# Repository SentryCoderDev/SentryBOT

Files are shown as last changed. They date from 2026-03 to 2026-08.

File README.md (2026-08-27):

# <p align="center">
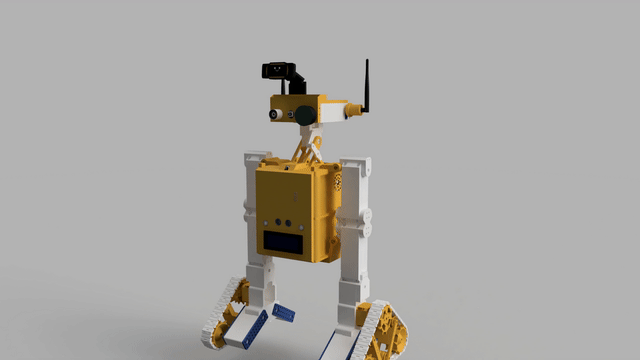
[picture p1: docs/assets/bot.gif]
SentryBOT demo
  
</p>

# SentryBOT – Modüler İki Ayaklı Yoldaş Robot Platformu













SentryBOT; Raspberry Pi 5 + Arduino tabanlı, modüler bir yoldaş robot ve servis mimarisidir. Tüm yetenekler bağımsız modüller hâlinde tasarlanır, tek bir Gateway üzerinden tek porttan API olarak sunulur. Donanım kontrolü Arduino ile yapılırken; konuşma tanıma/TTS, LED animasyonları, kamera ve LLM/RAG gibi fonksiyonlar Pi5 üzerinde mikro servisler olarak çalışır.

Ana hedefler:
- Basit, temiz, DryCode odaklı modüller
- Her modül hem kütüphane (import) hem servis (run) olarak çalışabilir
- Tüm konfigürasyonlar YAML dosyalarındadır ve gerektiğinde override edilebilir
- Donanım ağır işlerini Arduino üstlenir; görüntü işleme gibi pahalı işler gerekiyorsa dış istemcilere (PC) köprülenir

## Neler Yeni? (Öne Çıkan Son Geliştirmeler)

- **Tri-Layer Agent Mimarı (agent_core):** Robotun otonom kararları 3 katmanlı (Router/Planner, Uzman Sub-Agent'lar, Ana Persona) bir otonom ajan pipeline'ı ile yönetilir.
- **Social DB:** Eski JSON tabanlı izole hafızalar tek bir birleşik SQLite veritabanında toplandı. Kişiler, yüzler, ilişkiler, anılar ve ritüeller tek merkezden yönetiliyor.
- **OLED Faces:** SSD1306 I2C OLED için Pip tarzı prosedürel animasyonlu göz ve yüz ifadeleri eklendi. Duygusal ifadeler robotun durumuyla senkronize edilir.
- **Gelişmiş Otonomi ve Duygu Motoru (autonomy):** Robotun iç durumu (Mutluluk, Enerji, Merak, Korku) davranışlarını ve NeoPixel ışıklarını otomatik etkiler. Ses geldiğinde kafa çevirme, boşta kalınca iç çekme/etrafı izleme özellikleri aktiftir.
- **Wakeword Modülü:** OpenWakeWord destekli düşük güçlü arka plan dinleyicisi eklendi.
- **Semantik Router:** İstekler LLM tabanlı vektör/benzerlik ile en doğru sub-agent'a yönlendirilir.
- **Common Emotion Vocab:** Tüm modüller ortak bir duygu (emotion) sözlüğünü kullanır; gözler, ışıklar ve ses tonu birbiriyle uyumlu çalışır.
- Servo sürüşü I2C’ye taşındı (PCA9685, 50 Hz). Açı→mikrosaniye darbe haritalaması konfigüre edilebilir (min/max us).
- Çift “X‑cross” lazer eklendi: tekli ya da ikisi birden aç/kapa (firmware komut + Pi API).
- **Tam Yapılandırılmış Çıktı (Structured JSON)**: Ollama artık tüm yanıtlarını düşünce, vokal yanıt ve aksiyon içeren JSON formatında döner.
- **Sistem-Genel Modül Kontrolü**: Robot kendi modüllerini LLM kararlarıyla çalışma esnasında kapatıp açabilir.
- **Durum Kalıcılığı**: State Manager, global state'i sqlite/json backend ile restart sonrasında da saklar.
- **Gateway Güvenliği**: Gateway'e isteğe bağlı API anahtarı ve rol kontrolü eklendi; yazma uçları korunabilir.
- **VLM Mode Yönetimi**: Görüntü işleme yetenekleri ayrı ayrı açılıp kapatılabilir; pahalı işlemler ihtiyaca göre sınırlandırılır.
- **Multimodal Animasyon Senkronizasyonu**: Tek YAML akışında servolar, OLED göz ifadeleri ve NeoPixel ışık efektleri zaman uyumlu (time-coded) çalışır.

## Mimari Genel Bakış

- Donanım: Raspberry Pi 5 (ana bilgisayar) + Arduino (ör. Mega) kontrol kartı
- İletişim: Arduino ile NDJSON seri köprü; modüller arası HTTP (FastAPI)
- Gateway: Tüm modül router’larını tek FastAPI sürecinde birleştirir (varsayılan: 0.0.0.0:8080)
- Konfigürasyon: Her modül altında `config/config.yml`; merkezi düzenleme için Config Center
- Loglama: Merkezi log wrapper; dosya + bellek içi halka buffer

Başlatıcı akış (varsayılan): `sentrybot.py` -> TUI (Control Center) arayüzünü başlatır ve arka planda run_robot.py'yi çalıştırır.

## Robot Ne Yapar? (Yetenekler)

Algılama, karar ve ifade zinciriyle çalışan SentryBOT’un yetenekleri modüllere ayrılmıştır. Aşağıda her bir alan için kapsam, tipik veri akışı, önemli uç noktalar ve sınırlar özetlenmiştir.

- Hareket/Donanım
	- Arduino Seri Köprü (modules/arduino_serial)
		- Kapsam: servo/stepper sürüş, IK pozları, otur/kal kalk, IMU okuma, telemetry, emergency stop.
		- Veri akışı: Pi5 ↔ Arduino NDJSON satır tabanlı mesajlar; arkaplanda non-blocking okuyucu, heartbeat.
		- Örnek: POST `/arduino/request` body `{ "cmd": "set_pose", "pose":[...], "duration_ms":1200 }`
		- Sınırlar: Seri port stabilitesi; AUTO port bulma başarısızsa `ARDUINO_PORT` ile zorlayın.
	- PiServo “Kulaklar” (modules/piservo)
		- Kapsam: sol/sağ servo ile duygu jestleri ve basit jestler (wakeword/sound).
		- API: `/piservo/set?left=90&right=90`, `/piservo/emotion?name=joy`
		- Sınırlar: Donanım yoksa simülatör modunda çalışır; PWM/angle sınırları config ile belirlenir.
	- Teşhis & Zamanlama (modules/diagnostics, modules/scheduler)
		- Diagnostics API: `/diagnostics/run`, `/diagnostics/report` — modül sağlıklarını zincir hâlinde kontrol eder; gecikme ve tekrar eden hataları da değerlendirir.
		- Scheduler API: `/scheduler/jobs` — basit async periyodik görevler, HTTP ping işleri; runtime görev ekleme/silme de desteklenir.

- Duyular
	- Kamera (modules/camera)
		- Kapsam: PiCamera2/OpenCV backend; çözünürlük, FPS, JPEG kalitesi ayarlanabilir, son kare yayımcısı.
		- Kullanım: Gateway ile `/camera/*` altında stream ve snapshot uçları (modül README’sine bakın).
		- Sınırlar: PiCamera2 sürücü/firmware gereksinimleri; düşük ışıkta hız/kalite ayarı gerekebilir.
	- VLM Bridge (modules/vlm_bridge)
		- Kapsam: OpenCV tabanlı yüz algılama/tanıma ve takip; dış işlemci sonuçlarını Pi5’e HTTP ile yollar.
		- API: `POST /vlm/track { head_tilt, head_pan, drive? }` → Arduino “track” komutuna köprü.
		- Not: `POST /vlm/mode` ile objects/people/ocr/depth gibi yetenekler tek tek açılıp kapatılabilir.
		- Sınırlar: Ağ gecikmesi; kontrol döngüsünde stabilite için sınırlamalar (slew/ölü bant) önerilir.
	- Konuşma Tanıma (modules/speech)
		- Kapsam: SpeechRecognition ile çok dilli Google STT; I2S mikrofon; stereo’da DoA hesaplar.
		- API: `/speech/start`, `/speech/stop`, `/speech/last`, `/speech/direction`, `/speech/track/*`
		- Veri akışı: ALSA → çerçeveler → SpeechRecognition / Google STT → metin; stereo ise GCC-PHAT → açı.
		- Sınırlar: DoA için stereo şart.
	- Telemetri & Durum (modules/telemetry, modules/state_manager)
		- Telemetry: `/telemetry/metrics` Prometheus; `/telemetry/events` ham olay yayımı.
		- State Manager: `/state/get`, `/state/set/emotions`, `/state/set/<key>` — global durum ve duygular için kalıcı anahtar/değer desteği.

- İfade/Arayüz
	- Speak (TTS) (modules/speak)
		- Kapsam: pyttsx3 veya Piper ile offline TTS; base64 WAV oynatma; ALSA çıkış cihazı seçimi.
		- API: `/speak/say { text, engine? }`, `/speak/play { data: base64-wav }`
		- Sınırlar: Piper için model/binary gerekir; ses cihazı eşleşmesi (ALSA) şarttır.
	- NeoPixel (modules/neopixel)
		- Kapsam: Donanım/simülatör otomatik; ileri seviye animasyonlar ve duygusal renk paletleri.
		- API: `/neopixel/fill`, `/neopixel/effect`, `/neopixel/emote`, `/neopixel/animate`
		- Sınırlar: LED sayısı ve hız config’den alınır; ağır animasyonlarda CPU yükü artabilir.

		# NeoPixel API (user-facing notes)
		- `GET /neopixel/animations` — returns a curated, human-friendly list of available animations. Use `?show_all=true` to see every registered animation key.
		- `GET /neopixel/emotions` — returns a simple list of emotion names (e.g. `admiration`, `joy`). Color codes are intentionally hidden from the UI; the service will pick a random palette variant when an emotion is triggered.
		- `POST /neopixel/animate` — accepts a JSON body with fields `name` (animation key), optional `color` ("R,G,B" or "#RRGGBB") or `r,g,b` channels, optional `emotions` (list) and `iterations`.
		  Example body: `{ "name": "WAVE", "color": "0,255,255", "iterations": 2 }`
		- `POST /neopixel/emote` — convenience endpoint. Accepts `emotion` (single name), `emotions` (list) or `text`. If an `emotion` is provided, the server will randomly select one of the palette variants for that emotion and display it (no palette codes are returned in the API response for UI simplicity).
		- Behavior: The driver will attempt to play animations using the native Pi driver when available (hardware-accelerated). If the native driver does not support an animation name the server will fall back to Python implementations.
	- Interactions (modules/interactions)
		- Kapsam: Kurallara göre NeoPixel efektleri tetikleme; CPU sıcaklık/yük, ağ burst, olaylar.
		- API: `/interactions/event`, `/interactions/effect`, `/interactions/base`, `/interactions/state`
		- Sınırlar: NeoPixel servisi yoksa no-op; gelişmiş segment/mask için API genişlemesi önerilir.
	- Animasyon (modules/animate)
		- Kapsam: YAML tanımlı servo poz sekansları; `xAnimateService.run('name')` ile tetikleme.
		- Şema örneği: `name`, `loop`, `steps[{ pose[], duration_ms|hold_ms }]`.
	- Bildirimler (modules/notifier)
		- Kapsam: Telegram/Discord köprüleri; test ucu ve basit metin gönderimi.
		- API: `/notify/telegram`, `/notify/discord`, `/notify/test`

- Zeka
	- LLM (Ollama) (modules/ollama)
		- Kapsam: Kişilik (persona) yönetimi ile LLM sohbet; modül içi persona klasör yapısı.
		- API: `/ollama/chat`, `/ollama/persona`, `/ollama/personas`, `/ollama/persona/select`
		- Veri akışı: Speech → Ollama.chat → Speak; Interactions/NeoPixel opsiyonel duygusal tepki verebilir.

## Hızlı Başlangıç

1) Bağımlılıkları yükle (opsiyonel kolay kurulum scriptleri):
	 - Windows PowerShell veya Linux’ta kök dizinden çalıştırın: `install_all_requirements.py` ya da `install_all_requirements.sh`
	 - Donanım/harici yazılımlar (piper, ffmpeg, avrdude vb.) için ilgili modül README’lerine bakın

2) Gateway’i başlat (önerilen üretim modu):
	 - `python run_robot.py`
	 - Varsayılan adres: `http://localhost:8080`
	 - Örnek sağlık kontrolleri: `/neopixel/healthz`, `/speech/healthz`, `/arduino/healthz`

3) Tek modül olarak çalıştırma (geliştirme/test):
	 - Örnek: NeoPixel Servis → `uvicorn modules.visual_output.neopixel.xNeopixelService:create_app --factory --host 0.0.0.0 --port 8092`
	 - Örnek: Speech API → `python -m modules.voice.speech.xSpeechService --api`

Notlar:
- RPi5 üzerinde ALSA ses cihazları ve I2S mikrofon kart(lar)ı için sistem düzeyinde ayarlar gerekebilir (modül README’lerine bakın).
- Arduino bağlantısı için port otomatik bulunur; gerekirse `ARDUINO_PORT` ve `ARDUINO_BAUD` ile override.

## Docker ile Çalıştırma

Kök dizinde hazır Docker dosyaları bulunur:
- `Dockerfile`
- `docker-compose.yml`
- `modules/gateway/config/config.docker.yml`
- `docker-compose.full.yml`
- `modules/gateway/config/config.docker.full.yml`
- `docker-compose.rpi.yml`
- `modules/gateway/config/config.docker.rpi.yml`

1) Build + başlat:
	- `docker compose up --build -d`
2) Logları izle:
	- `docker compose logs -f sentrybot-gateway`
3) Durdur:
	- `docker compose down`

Varsayılan Docker konfigürasyonu donanım bağımlı modülleri kapalı getirir ve API çekirdeğini başlatır.

Full profil (tüm modüller include, autostart kapalı):
- `docker compose -f docker-compose.yml -f docker-compose.full.yml up --build -d`

Raspberry Pi 5 + Arduino profili (donanım modülleri açık):
- `docker compose -f docker-compose.yml -f docker-compose.rpi.yml up --build -d`

- Sağlık kontrolü: `http://localhost:8080/healthz`
- Swagger UI: `http://localhost:8080/docs`
- ReDoc: `http://localhost:8080/redoc`
- Modül include ayarlarını değiştirmek için `modules/gateway/config/config.docker.yml`, `modules/gateway/config/config.docker.full.yml` veya `modules/gateway/config/config.docker.rpi.yml` dosyalarını düzenleyin.
- Alternatif bir gateway config kullanmak için `GATEWAY_CONFIG` environment variable’ını override edin.
- Raspberry Pi/Linux cihaz eşlemeleri `docker-compose.rpi.yml` içinde hazırdır.

## Konfigürasyon

- Gateway yapılandırması: `modules/gateway/config/config.yml`
	- `server.host / server.port` (varsayılan: 0.0.0.0:8080)
	- `include.<module>` anahtarları ile modülleri aç/kapat
- Modül yapılandırmaları: Her modül altında `config/config.yml`
	- Örnek env değişkenleri: `ARDUINO_PORT`, `ARDUINO_BAUD`, `NEO_DEVICE`, `NEO_NUM_LEDS` …
- Canlı düzenleme: Config Center UI → `/config/ui` (Gateway açıkken)

## API Haritası (Özet)

Gateway açıkken tüm modül uçları tek porttadır. Genel sağlık uçları: `/<modül>/healthz`.

- Arduino Seri: `/arduino/*` – hello, request/send, telemetry
- VLM Bridge: `/vlm/track` – dış işlemci komut köprüsü
- Kamera: `/camera/*` – API/stream
- NeoPixel: `/neopixel/*` – efektler, duygular, animasyon
- Interactions: `/interactions/*` – kural motoru, event tetikleme
- Speak (TTS): `/speak/*` – say/play
- Speech (ASR/DoA): `/speech/*` – tanıma başlat/durdur, yön, takip
- Ollama: `/ollama/*` – chat, persona yönetimi
- PiServo: `/piservo/*` – kulak jestleri
- Telemetry: `/telemetry/*` – Prometheus `/metrics`, event
- Diagnostics: `/diagnostics/*` – self-check ve rapor
- State Manager: `/state/*` – global durum/emotions
- Scheduler: `/scheduler/*` – iş listesi
- Scheduler: `/scheduler/*` – iş listesi, dinamik görev ekleme/silme ve sonuç takibi
- Notifier: `/notify/*` – Telegram/Discord köprüleri
- Config Center: `/config/*` – YAML okuma/düzenleme, UI

Detaylar ve örnek istekler her modülün README’sinde mevcuttur.

## Donanım Özeti ve Notlar

- RPi5 ana bilgisayar, Arduino (ör. Mega) USB ile bağlı
- I2S mikrofon(lar) (stereo önerilir) → Offline ASR ve DoA için
- MAX98357A I2S DAC → hoparlör çıkışı (Speak modülü)
- WS2812/NeoPixel şerit + Jewel (7) + Stick (16) varsayılan haritalama
- İki mini servo (kulaklar) → PiServo
- Kamera: PiCamera2 veya USB Webcam (auto seçimi desteklenir)
- Görüntü işleme ağır ise bir PC’ye stream + VLM Bridge ile komut köprüleme

## Arduino Firmware Özeti ve Donanım Detayları

Arduino tarafı gerçek zamanlı I/O ve hareket kontrolünden sorumludur. NDJSON tabanlı satır‑satır komutlarla çalışır.

- I2C Servo Sürüş (PCA9685)
	- Frekans: 50 Hz. Kanallar: 0–15 (konfigürasyonla atanır).
	- Konfig makroları (örnek): `SERVO_USE_PCA9685=1`, `PCA9685_ADDR=0x40`, `SERVO_MIN_US=500`, `SERVO_MAX_US=2500`.
	- detach/reattach ve tam‑kapat (full‑off) kenar durumları ele alınmıştır.
- Lazerler (iki adet X‑cross)
	- Firmware komutu: `{ "cmd":"laser", "id":1|2, "on":true }`, `{ "cmd":"laser", "both":true, "on":true }`, `{ "cmd":"laser", "on":false }`.
	- Pi tarafı API: `/arduino/laser/one/{1|2}`, `/arduino/laser/both`, `/arduino/laser/off` (gateway altında).
- LCD 16×1 ekranlar
	- Donanımsal olarak 8×2 gibi adreslenir; 16 karakterlik satırlar 8+8 olarak yazdırılır (kutucuk sorunu çözülür).
- Ultrasonik, IMU, PID, Stepper
	- Komut yüzeyi: `set_servo`, `set_pose(duration)`, `leg_ik`, `stepper(pos/vel/cfg)`, `home/zero`, `pid on/off`, `stand/sit`, `imu_read/cal`, `eeprom save/load`, `tune`, `policy`, `track`, `telemetry_*`, `get_state`, `estop`.

Donanım bağlamaya dair pratik notlar:
- Pi↔Arduino seviye dönüştürücü yönü doğru olmalı (Pi→LV, Arduino→HV hatları). I2C için pull‑up’lar tek tarafta yeterlidir.
- PCA9685 beslemesi ve servo güç hattı kalın iletken ve ortak GND ile bağlanmalıdır.

## Hızlı API Örnekleri

Gateway çalışıyorsa tüm uçlar tek porttadır. Aşağıdaki istekler örnektir:

- Lazerleri kontrol et (Arduino üzerinden)
	- Tek lazer: POST `/arduino/laser/one/1`
	- Her ikisi: POST `/arduino/laser/both`
	- Kapat: POST `/arduino/laser/off`

- NeoPixel duygusal renk gösterimi
	- POST `/neopixel/emote` body: `{ "text": "joy curiosity", "duration": 0.25 }`

- Görüntü işleme köprüsü (dış istemci → servo)
	- POST `/vlm/track` body: `{ "head_pan": 20, "head_tilt": -5 }`

- Konuşma
	- ASR başlat/durdur: `/speech/start`, `/speech/stop`
	- TTS: `/speak/say` body: `{ "text": "Merhaba!" }`
	## Modüller (Tek Tek)

	- **agent_core**: 3-katmanlı LLM tabanlı otonom zekâ (Router, Sub-agents, Persona) ve epizodik bellek yönetimi.
	- **ai_provider**: (eski adıyla ollama) LLM sohbet ve persona yönetimi; LLM endpointleri.
	- **arduino_serial**: Arduino Mega ile NDJSON seri köprü. Servo, stepper, imu, telemetry ve lazer kontrolü (esp_link'i içerir).
	- **autonomy**: Live Mode. Duygu durum yönetimi (MoodManager), davranış döngüsü, VLM algı birleştirme ve otonom tepki/sahne yöneticisi.
	- **calibration**: Servo, Kamera ve Ses kalibrasyon yardımcıları.
	- **camera**: PiCamera2/OpenCV backend ile görüntü yakalama ve yayın.
	- **cognitive_memory**: (eski adıyla social_db) Kişiler, ilişkiler, görülme kayıtları, sohbet geçmişi ve anıları tek merkezde toplayan birleşik SQLite bellek.
	- **common**: Ortak yardımcılar, paylaşılan duygu/ifade (emotion) sözlüğü (`emotion_vocab.py`).
	- **expression**: Semantik ifade motoru. Sistem olaylarını senkronize animasyon, renk ve oled yüz ifadelerine dönüştürür (interactions'ı içerir).
	- **gateway**: Ana giriş noktası. Tüm modül router'larını tek bir FastAPI uygulamasında toplar.
	- **hardware**: RPi5 sağlık/sistem, I2C tarama, GPIO özet uyarıları.
	- **motion**: (eski animate ve piservo) YAML tabanlı servo sekansları ve kulak jestleri (I2C ve PWM).
	- **mutagen**: Mutagen CLI üzerinden dosya senkron yönetimi (cihaz ↔ robot).
	- **ota**: Over-the-air güncelleme altyapısı (örn: uzaktan Arduino firmware dağıtımı).
	- **runtime_console**: Logosuz, panel tabanlı sade terminal arayüzü / TUI görünümü (logwrapper'ı içerir).
	- **scheduler**: Dinamik zamanlanmış periyodik görevler ve HTTP ping işleri.
	- **system_control**: (eski state_manager, diagnostics, telemetry, config_center, notifier) Global sistem durumu, donanım/yazılım sağlık kontrolü, telemetri verileri ve yapılandırma yönetimi.
	- **visual_output**: (eski neopixel ve oled_faces) WS2812 LED animasyonları, renk paletleri ve SSD1306 prosedürel göz ifadeleri.
	- **vlm_bridge**: Yüz algılama/tanıma (OpenCV) ve Vision Language Model isteklerini işleyip donanım komutlarına dönüştürme.
	- **voice**: (eski speech, speak, wakeword) SpeechRecognition ASR, ses yönü, TTS ve OpenWakeWord dinleyicisi.

	## Tipik Senaryolar

	- Hedefe Bak (Görüntü → Servo): Dış istemci görüntüyü işler → `/vlm/track` ile açı gönderir → Arduino (PCA9685) pan/tilt yapar.
	- Konuş ve Yanıtla: `/speech/start` ile dinle → metni `/ollama/chat`’e gönder → yanıtı `/speak/say` ile seslendir → Interactions NeoPixel efekt tetikler.
	- Duruma Göre Işıklar: Interactions CPU ısısı/yük, ağ burst ve olay akışını izler → NeoPixel’de base/transient animasyonlar oynatır.
	- Lazer/LCD/Ultrasonik: `/arduino/laser/*` ile lazerleri tekli/ikili; ultrasonik ölçümleri LCD’de 16×1 uyumlu göster.

## Geliştirici Otomasyonları (GitHub Actions)

Repo, modül merkezli çalışma akışını destekleyen etiketleme ve yardımcı iş akışlarıyla gelir.

- PR Etiketleyici (otomatik)
	- Değişen dosya yollarından `modules/<ad>/...` ile modül adı bulunur ve `module: <ad>` etiketi eklenir.
	- Branch adına göre tür etiketi: `type: feature` (feat/*, feature-*) ve hedef branch etiketi: `target: dev`.
- Etiket Eşitleme
	- Depodaki etiketleri bir YAML tanımıyla senkron tutar (yeni modüllere renkli etiketler).
- Açık PR’ları Geriye Dönük Etiketleme
	- Actions → “Relabel Open PRs” → Run workflow. Değişen dosyalardan modül tespit eder; eksik etiket varsa oluşturur ve uygular.

Önerilen ek iş akışları (isteğe bağlı):
- Lint/Test (Ruff/Black/Pytest) — değişen modüllerle sınırlı koşum
- Arduino derleme kontrolü (`arduino-cli`) — firmware bütünlüğü
- actionlint/yamllint — workflow sağlığı
- pip‑audit/safety ve gitleaks — güvenlik taramaları

## Geliştirme Rehberi (DryCode)

- Her modül tek sorumluluk ve küçük bileşenlerden oluşur
- `x<ModuleName>Service.py` servis başlatıcıdır (app fabrikası + config yükleyici)
- Dosya yapısı örneği ve kurallar: `.github/copilot-instructions.md`
- Konfig değerleri yalnızca YAML’dan okunur; kodda hardcode edilmez
- Test edilebilirlik ve loglama önceliklidir

## Modüller ve Belgeler

- Gateway: modules/gateway/README.md
- Arduino Serial: modules/arduino_serial/README.md
- Hardware: modules/hardware/README.md
- Camera: modules/camera/README.md
- VLM Bridge: modules/vlm_bridge/README.md
- NeoPixel: modules/neopixel/README.md
- Interactions: modules/interactions/README.md
- Speak (TTS): modules/speak/README.md
- Speech (ASR/DoA): modules/speech/README.md
- PiServo: modules/piservo/README.md
- Animate: modules/animate/README.md
- State Manager: modules/state_manager/README.md
- Telemetry: modules/telemetry/README.md
- Scheduler: modules/scheduler/README.md
- Diagnostics: modules/diagnostics/README.md
- Notifier: modules/notifier/README.md
- OTA: modules/ota/README.md
- Mutagen: modules/mutagen/README.md
- Config Center: modules/config_center/README.md
- Log Wrapper: modules/logwrapper/README.md
- LLM (Ollama): modules/ollama/README.md

## Katkıda Bulunma

PR’ler ve öneriler memnuniyetle karşılanır. Yeni modül eklerken DryCode kurallarına ve modül şablonuna uyun. Küçük, okunabilir, test edilebilir değişiklikler tercih edilir.

## Sponsor ve Destek

Projeyi surdurulebilir sekilde gelistirmemize destek olmak isterseniz GitHub Sponsors uzerinden sponsor olabilirsiniz:

- https://github.com/sponsors/WhoIsMrSentry

Destek detaylari icin: `.github/SUPPORT.md`

## Lisans

SentryBOT NC-Atif 1.0 (Ticari Kullanim Yasak, Atif Zorunlu) — ayrintilar icin `LICENSE` dosyasina bakin.

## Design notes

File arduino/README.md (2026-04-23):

# SentryBOT Arduino Firmware

Bu dizin, SentryBOT Arduino firmware'ini içerir. Ana sketch `arduino/firmware/xMain/xMain.ino` altındadır. Firmware NDJSON satır-tabanlı protokolü korur, ancak üretim topolojisinde Pi ile doğrudan değil ESP bridge üzerinden haberleşir.

Üretim veri yolu:
- Pi -> ESP32: HTTP (`/send`, `/request`)
- ESP32 -> Mega: UART1 NDJSON
- Mega: mevcut tüm komutları (ekran, lazer, buzzer, stepper, servo) işlemeye devam eder

ESP bridge kodu: `arduino/firmware/esp_bridge/esp_bridge.ino`

Not: Mevcut firmware davranışı ve pin/kanal eşlemeleri kaynak kodundaki `xConfig.h` ile belirlenir. Eski README içeriklerinde bazı değerler farklı versiyonlardan kalma olabilir; bu dosya güncel `xConfig.h` tanımlarına göre düzenlenmiştir.

## Özellikler
- 4 Servo: baş (pan, tilt) + iki adet Pi-servo/aksesuar (varsayılan yapı: easing ile yumuşak hareket)
- 2 Stepper (skate): hız ve konum modları, Sit modunda dengeleme
- IMU: MPU6050 (I2C)
- NDJSON seri API @115200
- Modlar: Stand ve Sit/Skate
- Güvenlik: heartbeat timeout, estop, açı sınırları
- Kalıcılık: IMU offset EEPROM kaydet/yükle
- Tuning: PID, servo/stepper parametreleri canlı ayar

## RAM ve String Optimizasyonu
- Cute neopixel retry kuyruğu artık `String` payload yerine sabit `char` buffer kullanır.
- Legacy IR menü kopyalarında (sound/servo/sensors) geçici `String` birleştirmeleri azaltıldı.

Bu değişiklikler, AVR tarafta heap parçalanmasını azaltmak ve uzun çalışmada kararlılığı artırmak içindir.

## Bağlantı ve Kurulum
1) Seri port: `xConfig.h` içinde `SERIAL_IO_PORT` ile seçilir.
  - `0=Serial`, `1=Serial1`, `2=Serial2`, `3=Serial3`
  - Varsayılan: Mega kartlarda `1` (TX1/RX1, ESP bridge hattı), diğer kartlarda `1`
2) Gerekli kart/kütüphaneler: Arduino Mega 2560 (veya uyumlu), (opsiyonel) MFRC522, LiquidCrystal_I2C, Adafruit_MPU6050, AccelStepper
3) Yükleme: `arduino/firmware/xMain/xMain.ino`’yu açın, 115200 8N1.

## Servo Kontrolü (I2C PCA9685)
- `SERVO_USE_PCA9685` = 1 iken servolar I2C üzerinden PCA9685 ile sürülür (varsayılan: 1).
- `PCA9685_ADDR`, `SERVO_FREQ_HZ`, `SERVO_MIN_US`/`SERVO_MAX_US` `xConfig.h`’den ayarlanır.
- Mevcut `xConfig.h` konfigürasyonu için ana kanal eşlemesi:
  - `PIN_PAN` = 6 (head pan)
  - `PIN_TILT` = 9 (head tilt)
  - `PIN_PI_SERVO_1` = 7 (pi-servo 1)
  - `PIN_PI_SERVO_2` = 8 (pi-servo 2)

Not: Bu firmware sürümü `SERVO_COUNT_TOTAL = 4` ile derlenmiştir. Eğer 8-servo bacak kontrolü veya farklı bir kanal haritası istiyorsan `xConfig.h` ve ilgili kodlarda değişiklik gerekecektir.

## Güncel Pinler (xConfig.h ile uyumlu)
- Lazerler: `LASER1_PIN = 6`, `LASER2_PIN = 7` (polarite: `LASER_ACTIVE_HIGH`)
- Stepper STEP/DIR (şu anki `xConfig.h`):
  - `PIN_STEPPER1_STEP = 11`
  - `PIN_STEPPER1_DIR  = 12`
  - `PIN_STEPPER2_STEP = 9`
  - `PIN_STEPPER2_DIR  = 10`
- IR: `IR_PIN = 23`
- Buzzer: `BUZZER_LOUD_PIN = 2`, `BUZZER_QUIET_PIN = 3`
- Ultrasonik: `ULTRA_TRIG_PIN = 4`, `ULTRA_ECHO_PIN = 5`
- RFID (MFRC522): `RFID_SS_PIN = 53`, `RFID_RST_PIN = 49` (opsiyonel)

Bu değerler kodun kaynağındaki `xConfig.h` dosyasında tanımlıdır; fiziksel bağlantılarını bu değerlere göre doğrula.

## Lazer Kontrolü
- Tek lazer aç: `{ "cmd":"laser", "id":1, "on":true }` (veya id=2)
- Çift lazer aç: `{ "cmd":"laser", "both":true, "on":true }`
- Kapat: `{ "cmd":"laser", "on":false }`

## Ekran / Menü
Bu firmware tarafında 20x4 I2C LCD menü/durum ekranı desteklenir.

Yazılım notları:
- `xLcdHub` 20x4'ü hedef alacak şekilde çalışır. `LCD_COLS`/`LCD_ROWS` değerlerini `xConfig.h` içinde 20/4 olarak ayarlayabilirsin.
- OLED çizimi Arduino tarafında değil, Pi tarafındaki `modules/oled_faces` servisi tarafından sürülür.

## Dual Buzzer
- İki buzzer desteği: `BUZZER_LOUD_PIN` ve `BUZZER_QUIET_PIN`.
- Komut örnekleri:
  - `{ "cmd":"buzzer", "out":"loud", "freq":2200, "ms":60 }`
  - `{ "cmd":"sound_play", "name":"walle" }`

## IR Remote Kontrol (Menü + Parametre)
- IR alıcı pini: `IR_PIN` (varsayılan 2)
- Tuşlar firmware içinde şu string’lere çevrilir: `0..9`, `*`, `#`, `UP`, `DOWN`, `LEFT`, `RIGHT`, `OK`.

### Menü Kullanımı (kısa)
- HOME: `OK` menüyü açar; `UP/DOWN` ile gezinir, `OK` girer, `#` geri.
- Ana menü öğeleri: `SERVO`, `LASER`, `ULTRA`, `IMU`, `RFID`, `SOUND`, `REMOTE`, `CALIB`, `SYSTEM`.

## Komut Referansı (Özet)
- Ping: `{ "cmd":"hello" }`
- Heartbeat: `{ "cmd":"hb" }`
- Tek servo: `{ "cmd":"set_servo", "index":0, "deg":90 }`
- Poz (4 servo): `{ "cmd":"set_pose", "pose":[90,90,90,90], "duration_ms":1000 }`
- Stepper: `{ "cmd":"stepper", "id":0, "mode":"pos|vel", "value":1000, "drive":200 }`
- Stepper PID: `{ "cmd":"pid_enable", "id":0, "enable":true }`, `{ "cmd":"pid_set", "id":0, "kp":1.0, "ki":0.0, "kd":0.05, "target":100 }`
- Homing: `{ "cmd":"home" }`, sıfırlama: `{ "cmd":"zero_now" }`, `{ "cmd":"zero_set", "p1":0, "p2":0 }`
- IMU: `{ "cmd":"imu_read" }`, `{ "cmd":"imu_cal" }`
- EEPROM: `{ "cmd":"eeprom_save" }`, `{ "cmd":"eeprom_load" }`
- Telemetri: `{ "cmd":"telemetry_start", "interval_ms":50 }` / `{ "cmd":"telemetry_stop" }`

## Çevre Birimleri
- RFID (MFRC522): `{ "cmd":"rfid_last" }` ve olay yayını
- LCD (I2C 20x4): `{ "cmd":"lcd", "top":"LINE1", "bottom":"LINE2" }`
- Ultrasonik: `{ "cmd":"ultra_read" }`, kaçınma `{ "cmd":"avoid", "enable":true }`

## Lisans
Üst dizindeki `LICENSE` dosyasına bakın.

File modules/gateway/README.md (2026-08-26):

# Gateway

SentryBOT'un tek FastAPI sürecinde tüm modül router'larını birleştiren ana giriş kapısıdır. Üretim modunda robot tek port üzerinden hizmet verir.

## Sorumluluklar

- Modül router'larını mount etme ve başlatma (`bootstrap`)
- Merkezi sağlık, durum ve derin sağlık kontrolü
- İsteğe bağlı API anahtarı ve rol tabanlı güvenlik katmanı
- Modüller arası kablolama: Arduino↔NeoPixel, VLM↔Autonomy, Speech↔Interactions vb.
- `resolve_gateway_base_url` ile loopback URL çözümleme (modüller tarafından kullanılır)

## Mimari (Güncel: 2026-08-20)

- Giriş noktası: `xGatewayService.py`
- **Bootstrap** (parçalanmış):
  - `services/bootstrap.py` - Ana orchestration
  - `services/bootstrap_config.py` - Config helpers, agent section merge, runtime keys
  - `services/bootstrap_ai.py` - AI/Expression modülleri (vlm_bridge, autonomy, agent_core, expression, voice, animate, oled_faces)
  - `services/bootstrap_hardware.py` - Hardware modülleri (arduino, camera, neopixel, piservo, esp_link)
  - `services/bootstrap_ops.py` - Platform modülleri (social_db, logs, notifier, runtime_console, state_manager, scheduler, config_center)
- Çekirdek router: `api/router.py`
- URL yardımcıları: `url.py`
- Konfigürasyon: `config/config.yml` + `config/agent.yaml` birleşimi

## Bootstrap Davranışı

`bootstrap(app, cfg)` modülleri `include.<module>` bayraklarına göre yükler.

**Config.yml'deki `include` anahtarları (eski isimler - bootstrap map'inde yeni yollara yönlendirilir):**

| Config Key | Gerçek Modül Yolu | Bootstrap Fonksiyonu |
|---|---|---|
| `social_db` | `cognitive_memory` | `_include_social_db` |
| `arduino` | `arduino_serial` | `_include_arduino` |
| `esp_link` | `arduino_serial.transports.esp_transport` | `_include_esp_link` |
| `camera` | `camera` | `_include_camera` |
| `vlm_bridge` | `vlm_bridge` | `_include_vlm_bridge` |
| `neopixel` | `visual_output/neopixel` | `_include_neopixel` |
| `interactions` | `expression/interactions` | `_include_interactions` |
| `expression` | `expression` | `_include_expression` |
| `speak` | `voice/speak` | `_include_speak` |
| `wakeword` | `voice/wakeword` | `_include_wakeword` |
| `speech` | `voice/speech` | `_include_speech` |
| `ollama` | `ai_provider` | `_include_ollama` |
| `logs` | `runtime_console/logwrapper` | `_include_logs` |
| `animate` | `expression/animate` | `_include_animate` |
| `piservo` | `expression/piservo` | `_include_piservo` |
| `autonomy` | `autonomy` | `_include_autonomy` |
| `agent_core` | `agent_core` | `_include_agent_core` |
| `oled_faces` | `visual_output/oled_faces` | `_include_oled_faces` |
| `notifier` | `system_control/notifier` | `_include_notifier` |
| `runtime_console` | `runtime_console` | `_include_runtime_console` |

**Kritik modüller** (mount hatası `error` seviyesinde loglanır):
- `arduino`, `camera`, `autonomy`, `agent_core`, `speech`, `wakeword`, `speak`, `ollama`

**Import-tabanlı mount** (`_IMPORT_MODULES` - `system_control` alt modülleri):
- `telemetry` → `system_control.telemetry`
- `diagnostics` → `system_control.diagnostics`

**Opsiyonel mount** (ayrı fonksiyonlar):
- `state_manager` → `system_control/state_manager` (`_mount_state_manager`)
- `scheduler` → `system_control/scheduler` (`_mount_scheduler`)
- `config_center` → `system_control/config_center` (`_mount_config_center`)

**Bootstrap sonrası kablolama (wire functions):**
- `_wire_arduino_neopixel` - Arduino event `neopixel_request` → NeoRunner (ExpressionArbiter lease ile)
- `_wire_arduino_autonomy` - Arduino hardware events (cliff, bump, estop) → Autonomy brain
- `_wire_vlm_autonomy` - VLM bridge → Autonomy (vision context)
- `_wire_onsensor_vlm` - IMX500 bus → VLM bridge
- `_wire_head_arbiter` - HeadControlArbiter shared instance
- `_wire_animate_piservo` - Animate ↔ Piservo (ear channels)
- `_wire_interactions_piservo` - Interactions events → Piservo gestures
- `_wire_wakeword_interactions` - Wakeword → Interactions/NeoPixel
- `_wire_speech_interactions` - Speech → Interactions

## API

- `GET /healthz` — Startup durumu + modül bazlı sağlık
- `GET /status` — Include/start farkı
- `GET /health` — Derin sağlık taraması (httpx varsa)

Route listesi ayrı bir HTTP endpoint'i olarak sunulmaz; mount edilen tüm route'lar `api/router.py` içindeki `ROUTE_MANIFEST` sabitinde tutulur.

Mount edilen modüller kendi prefix'leri altında yayınlanır:
- `/arduino/*` - Arduino serial
- `/vlm/*` - VLM Bridge
- `/camera/*` - Camera
- `/neopixel/*` - Visual Output NeoPixel
- `/oled_faces/*` - Visual Output OLED
- `/expression/*` - Expression (semantic state, express tool)
- `/expression/animate/*` - Animate sequences
- `/expression/piservo/*` - Piservo ears
- `/expression/interactions/*` - Interactions rules
- `/voice/speech/*` - Speech ASR/DoA
- `/voice/speak/*` - Speak TTS
- `/voice/wakeword/*` - Wakeword
- `/autonomy/*` - Autonomy brain
- `/agent/*` - Agent Core
- `/cognitive/*` - Cognitive Memory (SocialDB)
- `/system/*` - System Control (telemetry, diagnostics, scheduler, state, config, notifier)
- `/ai_provider/*` - LLM Provider (Ollama)
- `/runtime_console/*` - TUI / Logs

## Konfigürasyon

`modules/gateway/config/config.yml`:
- `server.host`, `server.port` (default: 0.0.0.0:8080)
- `include.*` — Modül aç/kapa (yukarıdaki tablo)
- `security.enabled`, `security.api_key`, `security.admin_roles`
- `protected_get_prefixes` - Hassas GET uçları (camera, speech, state, telemetry, vlm, agent, autonomy, social)
- `arduino_neopixel_bridge.expression_lease` - Arduino NeoPixel bridge lease config

Güvenlik etkinse yazma uçları `X-API-Key` bekler; admin prefix'leri ek rol kontrolü uygular. `trust_loopback: true` ile localhost'tan key'siz erişim izin verilir.

## Çalıştırma

```bash
# Gateway tek başına
python -m modules.gateway.xGatewayService

# Üretim: run_robot.py (TUI + gateway + services)
python run_robot.py

# Docker
docker compose up --build -d
```

## İlişkiler

Gateway, projedeki modüller arası entegrasyonun omurgasıdır. Diğer modüller bağımsız servis olarak da çalışabilir (`uvicorn modules.xxx.xXxxService:create_app --factory`); ancak Pi5 üretim senaryosunda gateway tek süreç modelini sağlar.

**Önemli:** `config.yml` hala **eski modül isimlerini** kullanıyor (bootstrap `_include_map` yeni yollara yönlendirir). Gelecekte config.yml de yeni isimlere güncellenebilir.

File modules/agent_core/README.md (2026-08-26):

# Agent Core

SentryBOT'un konuşma odaklı ana ajan orkestratörüdür. `AgentOrchestrator`, kullanıcı isteğini veya olay tetiklerini alır; route eder, uygun araçları çalıştırır, bellek ve dünya durumunu kullanır ve son cevabı üretir.

## Sorumluluklar

- Tri-layer ajan akışı: Router/Planner, görev odaklı Sub-Agent'lar ve son Persona cevabı
- Tool-calling ve donanım güvenlik süzgeci (ExpressionArbiter lease sistemi)
- Epizodik bellek arama ve semantik sıralama (CognitiveMemory entegrasyonu)
- Dünya durumu ve SLAM konumu yüzeyi
- Eylem arbitrajı, ilerleme olayları ve gerçek zamanlı profil değiştirme

## Mimari (Güncel: 2026-08-20)

- Giriş noktası: `xAgentCoreService.py`
- Konfigürasyon: `config_loader.py` → merkezi `config/agent.yaml` (agent section)
- Ana orkestratör: `services/agent.py` → `AgentOrchestrator`
- **Yeni Tool Registry**: `services/tools/` (10 dosya: action_schemas, hardware_schemas, hardware_tools, http_client, motion_tools, perception_schemas, social_tools, tool_registry, tool_schemas, vision_tools)
- **Yeni Agent Parçaları**: `services/agent_context.py`, `agent_handlers.py`, `agent_memory_sync.py`, `agent_provider_parser.py`, `agent_streaming.py`, `agent_subagents.py`, `agent_turn.py`
- Yardımcı servisler: `memory.py`, `memory_consolidator.py`, `world_state.py`, `expression_arbiter.py`, `idle_behavior.py`, `tri_layer.py`
- **Arbiter'lar**: `action_arbiter.py` (aksiyon exclusive-lock hakemi), `speech_arbiter.py` (öncelikli TTS kuyruğu), `tool_execution_arbiter.py` (tool kaynak kilidi), `vision_arbiter.py` (VLM çağrı serileştirici)
- **Diğer**: `sensor_loop.py` (donanım sensör döngüsü), `semantic_index.py` (TF-IDF semantik router), `safety_filter.py` (girdi güvenlik filtresi), `slam.py`

Modül hem import edilebilir kütüphane hem de bağımsız FastAPI servisi olarak çalışır.

## Bağımlılıklar (Güncel)

- `autonomy`: Olay ve ajan koordinasyonu (brain.agent provider)
- `ai_provider` (eski `ollama`): LLM sağlayıcısı
- `system_control/config_center`: Merkezi config yükleme
- `runtime_console/logwrapper`: Merkezi log altyapısı
- `gateway`: URL çözümleme ve tek-port entegrasyon
- `common`: Ortak sözlükler (emotion_vocab), yardımcı fonksiyonlar
- `cognitive_memory` (eski `social_db`): Hafıza ve araç/kontrat yardımları
- `arduino_serial`: Donanım araçları için kontrat builder'lar
- `expression`: ExpressionArbiter (LED/servo/OLED lease)
- `vlm_bridge`: Vision tools için görüntü bağlamı

## API

Gateway altında `/agent/*` olarak yayınlanır.

### Core

- `GET /agent/healthz`
- `GET /agent/latency/latest`
- `GET /agent/latency/{trace_id}`
- `POST /agent/speech/interrupt`
- `POST /agent/step`
- `POST /agent/step_event`
- `POST /agent/step_stream`
- `POST /agent/route_preview`

### State and Memory

- `GET /agent/world_state`
- `GET /agent/memory/search`
- `GET /agent/slam/location`
- `GET /agent/slam/pathfind`

### Action Arbitration and Progress

- `GET /agent/actions/status`
- `GET /agent/arbiters/status`
- `GET /agent/arbiters/stream`
- `POST /agent/actions/queue`
- `POST /agent/actions/cancel`
- `POST /agent/progress`
- `POST /agent/events`
- `GET /agent/progress/latest`

### Runtime Profiles

- `GET /agent/profile`
- `POST /agent/profile/switch`

## Tool Registry (YENİ)

`services/tools/tool_registry.py` merkezi tool kayıt sistemi:
- **Hardware Tools**: servo, stepper, IMU, lazer, pose, IK, track, estop
- **Motion Tools**: animate sequences, piservo gestures
- **Perception Tools**: VLM track, face detect, scene analysis
- **Social Tools**: person upsert, chat episodes, preferences, relationships
- **Vision Tools**: capture frame, IMX500 status
- **Action Schemas**: JSON Schema tabanlı tool tanımları

Her tool: `schema` (JSON Schema), `handler` (async fn), `permissions` (hardware lease gerektirir mi?)

## Konfigürasyon

Bu modül merkezi `config/agent.yaml` içindeki `agent` bölümünü okur.

- `llm.provider`: `ollama` veya `google_ai_studio` (→ `ai_provider` modülü)
- `agent.model`, `agent.request_timeout`
- `tri_layer.*` (router, subagents, persona)
- `realtime_profile.*` (hız/kalite profilleri)
- `tools.hardware_lease_required`: donanım araçları için ExpressionArbiter lease

`ai_provider` profili aktifse model `qwen3.5:9b` olmalıdır.

## Kullanım

```python
from modules.agent_core.services.agent import AgentOrchestrator

agent = AgentOrchestrator(config, autonomy_client=client)
agent.start()
result = agent.step("Ortamı tara ve bana kimlerin burada olduğunu söyle.")
print(result["text"])
```

## İlgili Belgeler

- `architecture_agent_core.md`
- `MIGRATION_TRI_LAYER.md`
- `services/tools/__init__.py` docstring (tool registry detayları)

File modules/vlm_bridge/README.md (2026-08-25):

# VLM Bridge

SentryBOT'un görsel algı ve köprü modülüdür. Yerel OpenCV pipeline'ı veya uzak VLM sonuç ingest'i ile yüz/kişi/nesne bağlamını üretir; takip, hafıza ve otonomi entegrasyonunu sağlar.

## Sorumluluklar

- **Local mode**: Haar/OpenCV yüz algılama + ORB/FLANN tanıma + CSRT takip
- **Remote mode**: Dış işlemciden (PC) `/vlm/results` ingest (HTTP)
- **On-sensor mode**: IMX500 hardware accelerator (object detection)
- Yüz takibi, owner follow, **HeadControlArbiter** (priority lease)
- Kişi hafızası (`PersonIdentity`), görsel bağlam cache'i, semantic scene
- Autonomy'ye action dispatch (`apply_actions` → `/autonomy/apply_actions`)
- Vision event bus ve request gate (rate limiting, cooldown, budget)

## Mimari (Güncel: 2026-08-20) - **PARÇALANMIŞ**

- Giriş noktası: `xVlmBridgeService.py`
- **Processor Parçaları** (eski `services/processor.py` 1871 satır → 8 dosya):
  - `services/processor_init.py` → `VisionProcessor.__init__`, config, dependencies
  - `services/processor_vlm.py` → VLM client, budget gate, inference
  - `services/processor_identity.py` → `PersonIdentity` (face register, recognize, remember)
  - `services/processor_identity_events.py` → Identity event handlers
  - `services/processor_follow.py` → Follow mode (owner tracking, focus)
  - `services/processor_stream.py` → Stream processing, capture loop, IMX500
  - `services/processor_modes.py` → Mode management, profiles, categories
  - `services/processor_vlm_signals.py` → Vision signals, event bus
  - `services/runtime_vision.py` → Runtime vision context, living vision
- **Diğer Servisler**:
  - `services/action_dispatcher.py` → `ActionDispatcher` (autonomy apply_actions)
  - `services/face_manager.py` → Face detection/tracking (CSRT)
  - `services/google_vlm_client.py` → Google Cloud VLM / Gemini client
  - `services/llm_client.py` → LLM semantic scene generation
  - `services/head_control_arbiter.py` → **HeadControlArbiter** (priority lease, clamping)
  - `services/ollama_vlm_client.py` → Ollama VLM client
  - `services/cascade_loader.py` → Cascade yapılandırma yükleyici
  - `services/vision_event_bus.py` → Vision event bus
  - `services/semantic_describer.py` → Semantic scene açıklama üretimi
  - `services/face_emotion.py` → Yüz duygu analizi (FER)
  - `services/budgeted_inference.py` → Bütçe kontrollü VLM inference
- **API Parçaları**: `api/control.py`, `api/config_routes.py`, `api/analysis.py`, `api/person.py`

## Mod Yönetimi

- `processing_mode`: `local` | `remote` | `onsensor` (IMX500)
- **Production (Pi)**: `local` + `hybrid_local_capture: true` via `config/robot_execution_profiles.json` `vision`
- PC / YAML override: `follow_runtime_profile: false` keeps explicit remote ingest
- **Mod Bayrakları**: `objects`, `people`, `faces`, `depth`, `ocr`, `hazards`, `semantic_scene`
- **Kategori Haritası**: `local` / `remote` / `onsensor` hangi mod hangi kategoride çalışır
- **Profiller**: `balanced`, `people_focus`, `objects_focus`, `assistive`, `minimal`
- **Realtime Profiller**: `fast`, `normal` (VLM timeout/interval tuning)

## API (Gateway altında `/vlm/*`)

### Kontrol / Takip
- `POST /vlm/track` - Head pan/tilt komutu (HeadControlArbiter lease ile)
- `POST /vlm/follow/start|stop`, `GET /vlm/follow/status`
- `POST /vlm/follow/owner/start` - Owner follow mode
- `POST /vlm/focus/person` - Person focus
- `GET /vlm/head/status`, `POST /vlm/head/move`

### Mod / Profil
- `GET|POST /vlm/mode` - Mode bayrakları toggle
- `GET|POST /vlm/modes/categories` - Kategori haritası
- `GET /vlm/profile`, `POST /vlm/profile/switch` - Profil değiştir

### Sonuç / Bağlam
- `GET /vlm/results/latest` - Son VLM/OpenCV sonucu
- `POST /vlm/results` - Remote ingest (PC → Pi)
- `GET /vlm/context/latest` - Living vision context
- `POST /vlm/context/refresh` - Manuel refresh

### Analiz
- `POST /vlm/analyze` - Frame analizi (local/remote)
- `POST /vlm/ask` - VLM soru-cevap
- `POST /vlm/ocr` - OCR
- `POST /vlm/fer/analyze` - Facial emotion recognition
- `GET /vlm/video_feed` - MJPEG stream

### Yüz / Hafıza
- `POST /vlm/faces/register`, `GET /vlm/faces`
- `POST /vlm/person/remember`, `POST /vlm/person/relationship`
- `GET /vlm/person/{name}`, `GET /vlm/people`
- `POST /vlm/memory/chat`, `GET /vlm/memory/person`, `GET /vlm/memory/people`

### Assistive
- `POST /vlm/blind/start|stop` - Görme engelliler için scene description

## Konfigürasyon

Merkezi `config/agent.yaml` → `vlm_bridge` section + modül-içi `config/config.yml` (merge):

- `vision.processing_mode` - `local|remote|onsensor`
- `vision.hybrid_local_capture` - bool
- `vision_llm` / `google_vlm_client` - LLM/VLM client config
- `remote_multimodal` - PC endpoint config (`base_url`, `chat_endpoint`, `analyze_endpoint`)
- `actions.endpoint` - Genelde `/autonomy/apply_actions`
- `vision_request_gate` - Rate limit, cooldown, budget config
- `head_control_arbiter` - Priority, TTL, clamp settings

## İlişkiler (Güncel Modül Yolları)

- `autonomy` → Vision hooks, selamlama, world-memory beslemesi (`vision_context_bridge`)
- `camera` → Local capture kaynağı (`CameraCapture`, `Imx500Runner`)
- `arduino_serial` → Head/track komutları (HeadControlArbiter → `arduino.track()`)
- `expression/interactions` → Görsel olayların ifadeye dönüşümü
- `ai_provider` (eski `ollama`) / `google_vlm_client` → Semantic scene üretimi
- `cognitive_memory` (eski `social_db`) → Person/face memory persist
- `visual_output/oled_faces` → Face focus koordinasyonu

## HeadControlArbiter (KRİTİK)

Tüm head hareketi (track, follow, focus) **HeadControlArbiter**'dan geçer:
```python
arbiter.claim(source="vlm_follow", priority=85, ttl_s=1.0, pan=20, tilt=-5)
arbiter.clamp(pan, tilt)  # Deadband, slew rate, limits
```
- **Priority**: `animate` (90) > `vlm_follow` (85) > `autonomy_vision` (80) > `speech_doa` (70)
- **Clamping**: Deadband (0.5°), slew rate (deg/s), min/max limits
- **Bypass Riski**: `expression/animate` ve `autonomy` doğrudan `arduino.track()` çağırıyor!

## Bilinen Sorunlar

1. **Processor Parçalanma Tamamlandı Ama Facade Hala Var** - `VisionProcessor` artık thin facade olmalı, tüm mantık `processor_*.py`'larda.
2. **HeadControlArbiter Bypass** - `expression/animate` (animasyon sekansları) ve `autonomy/brain_parts/animations.py` doğrudan `arduino.track()` çağırıyor. **Tüm head hareketi arbiter'dan geçmeli.**
3. **Memory Yazma Çakışması** - `processor_identity.py` → `cognitive_memory` DB'sine yazıyor, `autonomy` de yazıyor. Transaction isolation yok.
4. **Budget Gate** - `vision_request_gate` + `vlm_inference_budget_gate` var ama `google_vlm_client` bazen bypass ediyor.

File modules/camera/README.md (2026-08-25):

# Perception - Camera

SentryBOT'un ana görüntü yakalama ve yayın modülüdür. PiCamera2 (veya OpenCV/USB fallback) ile kare yakalar, MJPEG yayınlar ve IMX500 on-sensor AI hattına kare sağlar.

## Sorumluluklar

- Canlı MJPEG video akışı (`/camera/video`)
- Tek kare snapshot (`/camera/snap`)
- IMX500/on-sensor algılama verisi sunumu (`/camera/onsensor/*`)
- Takip (tracking) hedef seçimi ve durum raporlama (`/camera/tracking/*`)
- Gateway üzerinden `perception/vision/vlm_bridge` ve diğer görsel modüllere kare kaynağı olma

## Mimari (Güncel: 2026-08-20)

- Giriş noktası: `xCameraService.py`
- **Yakalama**: `services/capture.py` → `CameraCapture`, `CaptureConfig`, `FramePublisher`
- **IMX500**: `services/imx500_runner.py` → `Imx500Runner`, `Imx500Config`
- **On-sensor Bus**: `services/onsensor_bus.py` → `OnSensorBus` (pub/sub)
- **Tracking**: `services/tracking.py` → takip hedef yönetimi
- **Capture Loops**: `services/capture_loops.py` — background capture task
- **Capture Bridge**: `services/capture_bridge.py` — VLM bridge için frame queue
- **Router**: `api/router.py`
- **Config**: `config_loader.py`

MCP graph'ta `CameraCapture` doğrudan gateway bootstrap (`_include_camera`) tarafından başlatılır.

## API (Gateway altında `/camera/*`)

### Stream
- `GET /camera/video` — MJPEG akış (boundary=frame)
- `GET /camera/snap` — tek kare JPEG

### Durum / Kontrol
- `GET /camera/healthz`
- `GET /camera/status` — `{ enabled, running, device, resolution, fps, imx500 }`
- `POST /camera/start` — capture başlat
- `POST /camera/stop` — capture durdur

### On-sensor / Tracking (IMX500)
- `GET /camera/onsensor/latest` — son on-sensor inference sonucu
- `GET /camera/tracking/tracks` — aktif track'ler
- `GET /camera/tracking/target` — seçili hedef
- `POST /camera/tracking/select` — hedef seç (`track_id`)

IMX500 için ayrı config endpoint'i yoktur; imx500 durumu `GET /camera/status` yanıtında bir alan olarak döndürülür.

## Konfigürasyon

Merkezi `config/agent.yaml` → `camera` section + modül-içi `config/config.yml` (merge):

```yaml
enabled: true
picamera2:
  size: { width: 1280, height: 720 }
  format: "RGB888"
  frame_rate: 30
  flip: "none"
imx500:
  enabled: true
  model_path: "/usr/share/imx500-models/imx500_network_ssd_mobilenetv2_fpnlite_320x320_pp.rpk"
  labels_path: ""
  confidence: 0.50
  iou: 0.65
  max_detections: 20
  preserve_aspect_ratio: true
  classes_of_interest: []
  tracker:
    iou_threshold: 0.30
    max_missed: 8
  target:
    label: "person"
    strategy: "largest"
```

## İlişkiler (Güncel Modül Yolları)

**Consumer (kare tüketici):**
- `perception/vision/vlm_bridge` → `VisionProcessor` local/hybrid mode için `CameraCapture` + `OnSensorBus` subscriber
- `autonomy` → vision context bridge için on-sensor results
- `agent_core/tools/vision_tools.py` → frame capture, status

**Provider (kare üretici):**
- `CameraCapture` → `FramePublisher` (pub/sub)
- `Imx500Runner` → `OnSensorBus` publisher
- `capture_bridge.py` → VLM bridge için async frame queue

**Platform:**
- `platform/telemetry` → camera metrics (fps, latency)
- `platform/diagnostics` → `/camera/healthz` check
- `platform/config_center` → runtime config apply (imx500 enabled, resolution)

## Processing Modları (VLM Bridge ile Koordineli)

| Mod | Açıklama | Camera Role |
|-----|---|---|
| `local` | Pi'de OpenCV face detect/track | `CameraCapture` + `FramePublisher` (CPU) |
| `remote` | PC'ye stream, PC VLM işler | `CameraCapture` stream only (MJPEG) |
| `onsensor` | IMX500 hardware accelerator | `Imx500Runner` + `OnSensorBus` (NPU) |
| `hybrid` | Local capture + remote VLM | `CameraCapture` + `capture_bridge` queue |

`config/robot_execution_profiles.json` → `vision.processing_mode` + `vision.hybrid_local_capture` ile kontrol.

## Bilinen Sorunlar (KRİTİK)

1. **Device Lock / Mode Switching Yok** - `CameraCapture` (PiCamera2) VE `Imx500Runner` **aynı `/dev/video0`**'ı açmaya çalışıyor. `hybrid_local_capture: true` + `mode: local` ikisi de aktifse → **device busy crash**. **`modules/camera/device_manager.py` (YENİ GEREKLİ)** singleton device lock + reference count + mode switching merkezi olmalı.

2. **Capture Bridge Duplicate Logic** - `services/capture_bridge.py` + `services/capture_loops.py` + `services/capture.py` frame publishing logic'i **3 yerde tekrar ediyor**. Tek `FrameSource` abstraction ile birleştirilmeli.

3. **IMX500 Runner Config Drift** - `Imx500Runner` config `Imx500Config` dataclass ama `config_loader.py` merge sonrası dict. Type safety yok. `pydantic` model ile validation.

4. **Healthz Device Check Eksik** - `/camera/healthz` device açık mı kontrol etmiyor, sadece service running döndürüyor.

4. **USB Camera Fallback Test Edilmemiş** - `picamera2` import fail olursa OpenCV `VideoCapture` fallback var ama CI/CD'de test yok.

5. **Resolution/FPS Change Runtime** - `POST /camera/config` yok, capture restart gerekiyor. Dynamic reconfig desteği eklenmeli.

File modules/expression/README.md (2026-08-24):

# Expression

SentryBOT'un semantik ifade orkestrasyon modülüdür. Sistem olaylarını ve duygu komutlarını LED, OLED, ses, kafa ve kulak modalitelerine atomik biçimde dağıtır.

## Sorumluluklar

- Olay → semantik ifade durumu eşlemesi (`SemanticExpressionEngine`)
- Çoklu modalite koordinasyonu (`ExpressionArbiter`) - **Lease tabanlı arbitraj**
- LLM tool endpoint'i: `/expression/express`
- `common.emotion_vocab` tabanlı render sözlüğü
- Output bridge ile legacy hedeflere uygulama

## Mimari (Güncel: 2026-08-20)

- Giriş noktası: `xExpressionService.py` (thin facade, <100 satır)
- **Semantik Motor**: `services/state.py` → `SemanticExpressionEngine` + `services/state_events.py`
- **Arbiter**: `services/arbitrator.py` → `ExpressionArbiter` (priority lease, visual lock, modality clients)
- **Çıkış Köprüsü**: `services/output_bridge.py` → Legacy hedeflere plan/apply
- **Adapters**: `services/adapters/head_adapter.py` (kafa kontrolü)
- **Router**: `semantic/api/router.py` (kök `api/router.py` artık 2 satırlık re-export shim)

### Alt Modüller (Expression Kapsamında)

| Alt Modül | Yol | Sorumluluk |
|---|-----|---|
| **Animate** | `expression/animate/` | YAML tabanlı servo sekansları (sit, blink, look_around, owner_scan, vb.) |
| **Piservo** | `expression/piservo/` | Kulak servo jestleri (PWM/I2C), duygu→kulak pozisyonu |
| **Interactions** | `expression/interactions/` | Kural tabanlı NeoPixel/LED efekt tetikleme (CPU, network, events) |

Graph'ta gateway `_include_expression` `xExpressionService` oluşturur ve `router.set_arbiter(...)` ile `/express` yolunu bağlar. `voice/speak` modülü `speak.started/finished` olaylarını expression katmanına gönderir.

## API (Gateway altında `/expression/*`)

### Durum
- `GET /expression/state`
- `GET /expression/status`
- `GET /expression/history`

### Olay / Manuel
- `POST /expression/event`
- `POST /expression/state`
- `POST /expression/output/apply`

### Atomik İfade (LLM Tool)
- `POST /expression/express`
  - `emotion`, `intensity`, `duration_s`
  - `modalities`: `leds`, `oled`, `voice`, `head`, `ears`
  - opsiyonel `text`, `language`, `force`

### Sözlük
- `GET /expression/vocab`
- `GET /expression/render/{emotion}`

### Output Bridge (Legacy)
- `GET /expression/output/status`
- `GET /expression/output/plan`
- `POST /expression/output/apply`

## Konfigürasyon

Modül-içi `config/config.yml` + merkezi `config/agent.yaml` (expression section):
- Olay → ifade eşleme kuralları (`event_map`)
- Modality client URL'leri (`adapters.gateway_url`)
- Rate limit / visual lock ayarları (`visual_lock_ms`, `min_interval_ms`)

## İlişkiler (Güncel Modül Yolları)

**Çıkış Modaliteleri (Arbiter Client'ları):**
- `visual_output/neopixel` → LED animasyonları, companion modes
- `visual_output/oled_faces` → OLED göz ifadeleri, mood/activity render
- `expression/piservo` → Kulak servo jestleri
- `arduino_serial` → Kafa hareketi (head_adapter üzerinden, **HeadControlArbiter lease zorunlu**)
- `voice/speak` → TTS prosody (tone, rate, pitch)

**Olay Kaynakları:**
- `expression/interactions` → Metrik olaylar (CPU, network, companion)
- `autonomy` → Mood, idle action, companion goal olayları
- `voice/speak` → `speak.started`, `speak.finished` (ses senkronizasyonu)
- `vlm_bridge` → Vision focus, person detected
- `voice/wakeword` → Wakeword detected

**Ortak Sözlük:**
- `common.emotion_vocab` → Tek duygu taksonomisi (canonical name, render hints, valence, arousal)

## ExpressionArbiter Lease Sistemi (KRİTİK)

Tüm donanım modaliteleri (LED, OLED, Servo/Head, Ears) **lease** alır:
```python
arbiter.claim_lights(source="autonomy", priority=80, ttl_s=2.0, force=False)
arbiter.claim_servo(source="animate", priority=90, ttl_s=1.5)
arbiter.claim_oled(source="autonomy", priority=70)
```
- `priority`: Yüksek kazanır (animate=90, autonomy=80, interactions=60)
- `ttl_s`: Otomatik release süresi
- `force`: Mevcut lease'i ez (dikkatli kullan)

## Kanonik Ağaç Notu

`semantic/` altındaki uygulama **kanoniktir** ve kök `xExpressionService.py` shim'i üzerinden mount edilir. `services/` altındaki eski ağaç yalnızca testlerin kullandığı legacy bir kopyadır ve birleştirme planındadır.

## Bilinen Sorunlar

1. **HeadControlArbiter Bypass** - `expression/animate` ve `autonomy` doğrudan `arduino.track()` çağırıyor, `ExpressionArbiter` lease alıyor ama `HeadControlArbiter` (vlm_bridge) ayrı bir sistem. **İki arbiter birleştirilmeli.**

## Çözülen Sorunlar

- ~~**xExpressionService Çok Büyük** (4209 satır)~~ — ✅ ÇÖZÜLDÜ: Kök `xExpressionService.py` artık 2 satırlık shim; kanonik implementasyon `semantic/` ağacında.

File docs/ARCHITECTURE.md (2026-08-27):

# SentryBOT — Uçtan Uca Mimari ve İş Akış Haritası

SentryBOT devasa ve dağıtık çalışan bir platformdur. Yazılım altyapısının sürdürülebilir olması için devasa tekil dokümanlar yerine, her modül spesifik kendi mimari, `if/else`, hata yakalama (try/catch) ve lokal veri akış detaylarını kendi klasöründe tutar.

Bu doküman, robotun **Büyük Resmini (Big Picture)** çizmek ve alt modüllerin dokümanlarına erişmek için bir **Merkez İstasyon** (Index) görevi görür.

---

## 🗂️ Modül İçerik (Mimari) Dosyaları

Aşağıdaki bağlantılara tıklayarak, her modülün kendi iç mantık yapısına (Flowchart'lar, Karar Ağaçları, Pydantic/JSON fallback yapıları) ulaşabilirsiniz:

| Modül Kategori | Bileşen Adı | Detaylı Mimari Dokümanı | Görevi |
|---|---|---|---|
| **Çekirdek** | Gateway | [architecture_gateway.md](../modules/gateway/architecture_gateway.md) | Mikroservisleri ayaklandıran API Bootstrapper |
| | Autonomy (Brain) | [architecture_autonomy.md](../modules/autonomy/architecture_autonomy.md) | Sense-Think-Act döngüsü, duygu bozunması, LLM kararları |
| | Arduino Serial | [architecture_arduino_serial.md](../modules/arduino_serial/architecture_arduino_serial.md) | NDJSON seri haberleşme, port polling ve arka plan thread kuyruğu |
| **Görsel Algı** | VLM Bridge | [architecture_vlm_bridge.md](../modules/vlm_bridge/architecture_vlm_bridge.md) | OpenCV yüz algılama, ORB/FLANN eşleme ve CSRT takip |
| | Camera | [architecture_camera.md](../modules/camera/architecture_camera.md) | MJPEG publisher stream, düşme anı auto-recovery restart mekanizması |
| **Ses & Dil** | Speech | [architecture_speech.md](../modules/speech/architecture_speech.md) | Çok kanallı ASR, ses gelişi (DOA) yön hesaplama filtresi |
| | Wakeword | [architecture_wakeword.md](../modules/wakeword/architecture_wakeword.md) | Sürekli dinleme, trigger sleep/wake timer geçişleri |
| | Speak (TTS) | [architecture_speak.md](../modules/speak/architecture_speak.md) | Ton/duygu if (happy/sad) hız ayarlaması, Markdown Regex temizliği |
| | Ollama (LLM) | [architecture_ollama.md](../modules/ollama/architecture_ollama.md) | Pydantic JSON validate try/catch ve XML regex ayrıştırıcı fallback adımları |
| **Etkileşim** | Interactions | [architecture_interactions.md](../modules/interactions/architecture_interactions.md) | CPU temp, Ağ yükü kural motoru (Rule Engine önceliklendirmesi) |
| | NeoPixel | [architecture_neopixel.md](../modules/neopixel/architecture_neopixel.md) | 23 Duygu paleti random renk çözümleme, SPI vs Simulator donanım seçimi |
| | Animate | [architecture_animate.md](../modules/animate/architecture_animate.md) | YAML step parsing, duyguya göre speed hesaplama, thread tabanlı oynatma |
| | State Manager | [architecture_state_manager.md](../modules/state_manager/architecture_state_manager.md) | Thread-safe Mutex lock'lar veri ezmeyi (`copy.deepcopy`) engelleme |

*(Log, Notifier, Telemetry, Scheduler, OTA gibi basit yardımcı (utility) modüller mimari doküman gerektirmeyecek kadar sadedir, Gateway üzerinden API yansıtırlar).*

---

## 🌐 Üst Düzey Sistem Etkileşim ve Veri Akış Modeli (Kuşbakışı)

SentryBOT'un tüm yapısını birbirine bağlayan ağaç. Autonomy Brain sistemin kalbindedir. `if` okları sistemin neyi seçtiğini ifade eder.

```mermaid
flowchart LR
    subgraph LAYER_SENSE ["1. ALGI VE SENSOR KATMANI"]
        direction TB
        subgraph SG_CAMERA ["CAMERA Modülü"]
            direction TB
            %% Ana Thread
            CAMERA_START_THREAD([Kamera Capture Thread]) --> CAMERA_HW_INIT(Donanıma Bağlan: /dev/video0)
            
            CAMERA_HW_INIT --> CAMERA_CHK_HW{"Kamera Cihazı<br>Açıldı mı?"}
            
            CAMERA_CHK_HW -- Hayır --> CAMERA_LOG_ERR[Hata: Kamera Bulunamadı] --> CAMERA_RETRY_WAIT(Saniye Bekle, Tekrar Dene) --> CAMERA_HW_INIT
            CAMERA_CHK_HW -- Evet --> CAMERA_ENTER_LOOP[Okuma Döngüsüne Gir]
            
            %% Çerçeve / Frame Okuma Döngüsü
            subgraph Capture Loop [Sürekli Okuma Döngüsü]
            CAMERA_ENTER_LOOP --> CAMERA_GRAB_FRAME(Kareyi Kapat - read)
            
            CAMERA_GRAB_FRAME --> CAMERA_CHK_FRAME{"Kare Başarılı <br> Geldi mi?"}
            CAMERA_CHK_FRAME -- Hayır --> CAMERA_LOG_DROP[Uyarı: Frame Dropped] --> CAMERA_RECONN_HW(Cihazı Kapat / Yeniden Aç) --> CAMERA_ENTER_LOOP
            
            CAMERA_CHK_FRAME -- Evet --> CAMERA_FPS_THROTTLE{"Hedef FPS<br>Geçildi mi?"}
            CAMERA_FPS_THROTTLE -- Evet --> CAMERA_SKIP((Kareyi Atla)) --> CAMERA_GRAB_FRAME
            
            CAMERA_FPS_THROTTLE -- Hayır --> CAMERA_ENCODE_JPEG(CAMERA_JPEG Olarak Sıkıştır)
            end
            
            %% Frame Publishing
            subgraph Publisher CAMERA_API [Yayın Mekanizması]
            CAMERA_ENCODE_JPEG --> CAMERA_LOCK_VAR[CAMERA_MUTEX Kilidi Al]
            CAMERA_LOCK_VAR --> CAMERA_UPDATE_VAR{"global_frame değişkenini<br>güncelle"}
            CAMERA_UPDATE_VAR --> CAMERA_UNLOCK_VAR[CAMERA_MUTEX'i Bırak]
            CAMERA_UNLOCK_VAR --> CAMERA_SIGNAL_EVENT(Tüm bekleyen web<br>istemcilerine Event Yolla)
            end
            
            CAMERA_SIGNAL_EVENT --> CAMERA_GRAB_FRAME
            
            %% Web Stream İstemcileri
            CAMERA_API_REQ([CAMERA_GET /camera/stream]) --> CAMERA_WEB_LOOP[Sonsuz Yield Döngüsü]
            CAMERA_WEB_LOOP --> CAMERA_WAIT_EVT(Signal Bekle)
            CAMERA_WAIT_EVT --> CAMERA_READ_F(CAMERA_global_frame'i oku)
            CAMERA_READ_F --> CAMERA_SEND_F(CAMERA_HTTP Multi-part olarak Yolla) --> CAMERA_WEB_LOOP
        end
        subgraph SG_HARDWARE ["HARDWARE Modülü"]
            direction TB
            %% Veri Toplama Akışı
            HARDWARE_START("GET /hardware/info") --> HARDWARE_GET_CPU("psutil.cpu_percent")
            HARDWARE_GET_CPU --> HARDWARE_GET_RAM("psutil.virtual_memory")
            HARDWARE_GET_RAM --> HARDWARE_GET_TEMP("vcgencmd measure_temp")
            HARDWARE_GET_TEMP --> HARDWARE_GET_I2C("i2cdetect cihazlarını tara")
            
            HARDWARE_GET_I2C --> HARDWARE_CHK_THROTTLE{"Sistem<br>Throttle Yiyor mu?"}
            
            HARDWARE_CHK_THROTTLE -- "Evet (Under-voltage veya Overheat)" --> HARDWARE_SET_WARN("Uyarı: Besleme veya Soğutma Yetersiz")
            HARDWARE_CHK_THROTTLE -- "Hayır" --> HARDWARE_SET_OK("Sistem Normal")
            
            HARDWARE_SET_WARN --> HARDWARE_BUILD_JSON("JSON Birleştir")
            HARDWARE_SET_OK --> HARDWARE_BUILD_JSON
            HARDWARE_BUILD_JSON --> HARDWARE_RET_OK("Arayüze Gönder")
        end
        subgraph SG_SPEECH ["SPEECH Modülü"]
            direction TB
            %% Ana Giriş
            SPEECH_START([Mikrofon Dinleme Döngüsü]) --> SPEECH_CAPTURE_AUDIO[Ses Akışını Yakala]
            
            %% Ses Yönü Bulma
            subgraph SPEECH_Direction_Calculation ["Ses Yönü Tahmini"]
            SPEECH_CAPTURE_AUDIO --> SPEECH_CHK_DIR_SUPPORT{"Cihaz Çok Kanallı mı? <br> (Örn: ReSpeaker)"}
            SPEECH_CHK_DIR_SUPPORT -- Evet --> SPEECH_CALC_DOA(SPEECH_DOA - Direction of Arrival <br> Hesapla)
            SPEECH_CHK_DIR_SUPPORT -- Hayır --> SPEECH_SKIP_DIR[Varsayılan 0° / İleri]
            
            SPEECH_CALC_DOA --> SPEECH_SET_DIR_VAR[Global Ses Yönü Değişkenini<br>Güncelle]
            SPEECH_SKIP_DIR --> SPEECH_SET_DIR_VAR
            end
            
            %% Konuşma Tanıma
            subgraph SPEECH_Speech_Recognition ["Konuşma Tanıma ASR"]
            SPEECH_SET_DIR_VAR --> SPEECH_VAD_CHK{"Ses Var mı? <br> Voice Activity Detection"}
            
            SPEECH_VAD_CHK -- Hayır --> SESSİZLIK((Bekle)) --> SPEECH_CAPTURE_AUDIO
            SPEECH_VAD_CHK -- Evet --> SPEECH_SEND_ASR[Ses Verisini <br> Recognizer Motoruna İlet]
            
            SPEECH_SEND_ASR --> SPEECH_RECOGNIZER_ENGINE(SpeechRecognition / Google STT)
            
            SPEECH_RECOGNIZER_ENGINE --> SPEECH_PARSE_RES{"Motor Sonuç <br> Döndürdü mü?"}
            SPEECH_PARSE_RES -- Hayır / Gürültü --> SESSİZLIK
            SPEECH_PARSE_RES -- Evet --> SPEECH_EXTRACT_TEXT[Tanınan Metni Al]
            
            SPEECH_EXTRACT_TEXT --> SPEECH_SET_LAST_SPEECH(SPEECH_last_speech_text <br>değişkenini güncelle)
            end
            
            SPEECH_SET_LAST_SPEECH --> SPEECH_AUTONOMY_PULL[Autonomy Modülü<br>Tarafından Poll Edilmeyi Bekle]
            SPEECH_AUTONOMY_PULL --> SESSİZLIK
        end
        subgraph SG_VLM_BRIDGE ["VLM_BRIDGE Modülü"]
            direction TB
            VLM_BRIDGE_START([Kamera / Remote Ingest]) --> VLM_BRIDGE_MODE{processing_mode}

            VLM_BRIDGE_MODE -- local --> VLM_BRIDGE_FACE_DET[Haar Face Detect]
            VLM_BRIDGE_FACE_DET --> VLM_BRIDGE_IDENT[ORB + FLANN ile yüz kimliği]
            VLM_BRIDGE_IDENT --> VLM_BRIDGE_RESULTS[latest_results güncelle]

            VLM_BRIDGE_RESULTS --> VLM_BRIDGE_FOLLOW{follow active}
            VLM_BRIDGE_FOLLOW -- Hayır --> VLM_BRIDGE_NORMAL[alerts + semantic + memory]
            VLM_BRIDGE_FOLLOW -- Evet --> VLM_BRIDGE_LOCK{CSRT kilidi var mı?}
            VLM_BRIDGE_LOCK -- Hayır --> VLM_BRIDGE_LOCK_FACE[Hedef yüz seç ve tracker kilitle]
            VLM_BRIDGE_LOCK -- Evet --> VLM_BRIDGE_UPDATE[CSRT bbox güncelle]
            VLM_BRIDGE_LOCK_FACE --> VLM_BRIDGE_TRACK
            VLM_BRIDGE_UPDATE --> VLM_BRIDGE_TRACK[Pan/Tilt hesapla ve /vlm/track gönder]

            VLM_BRIDGE_MODE -- remote --> VLM_BRIDGE_INGEST[POST /vlm/results]
            VLM_BRIDGE_INGEST --> VLM_BRIDGE_VALIDATE[Auth + normalize]
            VLM_BRIDGE_VALIDATE --> VLM_BRIDGE_REMOTE_RES[latest_results güncelle]
            VLM_BRIDGE_REMOTE_RES --> VLM_BRIDGE_REMOTE_FLOW{follow active}
            VLM_BRIDGE_REMOTE_FLOW -- Evet --> VLM_BRIDGE_SKIP[Remote action akışını bastır]
            VLM_BRIDGE_REMOTE_FLOW -- Hayır --> VLM_BRIDGE_NORMAL
        end
        subgraph SG_WAKEWORD ["WAKEWORD Modülü"]
            direction TB
            %% Ana Giriş
            WAKEWORD_START([Arka Plan Dinleme Thread'i]) --> WAKEWORD_SETUP_WW_ENGINE(Wakeword Motorunu Başlat <br> Porcupine / Snowboy)
            
            WAKEWORD_SETUP_WW_ENGINE --> WAKEWORD_WAIT_AUDIO[Mikrofondan Küçük<br>WAKEWORD_PCM Chunk'lar Oku]
            
            %% Arka Plan Döngüsü
            subgraph Background Listening [Srekli Dinleme ve Tetikleme]
            WAKEWORD_WAIT_AUDIO --> WAKEWORD_CHK_WAKEWORD{"Motor: 'Hey Sentry'<br>dedi mi?"}
            
            WAKEWORD_CHK_WAKEWORD -- Hayır --> WAKEWORD_DISCARD_CHUNK[Sesi Çöpe At] --> WAKEWORD_WAIT_AUDIO
            
            WAKEWORD_CHK_WAKEWORD -- Evet --> WAKEWORD_TRIGGER_ACT(Wakeword Algılandı <br> 'WAKEWORD__on_wakeword')
            end
            
            %% Tetikleme Sonrası İşlemler
            subgraph Trigger Actions [Tetikleme Aksiyonları]
            WAKEWORD_TRIGGER_ACT --> WAKEWORD_START_SPEECH_API(WAKEWORD_POST /speech/start <br> Konuşma Tanımayı Aç)
            WAKEWORD_START_SPEECH_API --> WAKEWORD_PUSH_EVENT(WAKEWORD_POST /interactions/event <br> 'wakeword.detected')
            
            WAKEWORD_PUSH_EVENT --> WAKEWORD_SOUND_CB{"Bip Sesi <br> Açıksa"}
            WAKEWORD_SOUND_CB -- Evet --> WAKEWORD_ARDU_BEEP(WAKEWORD_POST /arduino/send <br> buzzer bip)
            WAKEWORD_SOUND_CB -- Hayır --> WAKEWORD_START_WINDOW(Komut Dinleme Süresi Başlat)
            
            WAKEWORD_ARDU_BEEP --> WAKEWORD_START_WINDOW
            
            WAKEWORD_START_WINDOW --> WAKEWORD_TIMER_WAIT{"Bekle:<br>command_window_s <br>(Örn: 5 sn)"}
            
            WAKEWORD_TIMER_WAIT -- Süre Dolduğunda --> WAKEWORD_STOP_SPEECH_API(WAKEWORD_POST /speech/stop <br> Konuşma Tanımayı Kapat)
            end
            
            WAKEWORD_STOP_SPEECH_API --> WAKEWORD_WAIT_AUDIO
        end
    end
    subgraph LAYER_CORE ["2. MERKEZI KARAR VE YONETIM - BEYIN"]
        direction TB
        subgraph SG_AUTONOMY ["AUTONOMY Modülü"]
            direction TB
            %% Ana Döngü
            AUTONOMY_START_LOOP((Tick Döngüsü)) --> AUTONOMY_SENSE[AUTONOMY_SENSE: Algı Verilerini Topla]
            
            %% SENSE KISMI
            subgraph AUTONOMY_SENSE_PHASE ["Sense - Algılama"]
            AUTONOMY_S_SPEECH{"Yeni Konuşma<br>Var mı?"}
            AUTONOMY_S_DIR{"Ses Yönü<br> Değişti mi?"}
            AUTONOMY_S_VIS{"Görüntüde<br>Kişi Var mı?"}
            
            AUTONOMY_S_SPEECH -- Evet --> AUTONOMY_S_ADD_TXT(Konuşma Metnini Al)
            AUTONOMY_S_DIR -- Açı Değişimi > 10° --> AUTONOMY_S_TURN[O yöne kafayı çevir]
            AUTONOMY_S_VIS -- Evet --> AUTONOMY_S_MOOD_B[MoodManager'a<br>Mutluluk Puanı Ekle]
            end
            
            AUTONOMY_SENSE --> AUTONOMY_SENSE_PHASE
            AUTONOMY_SENSE_PHASE --> AUTONOMY_THINK[AUTONOMY_THINK: Düşün ve Karar Ver]
            
            %% THINK KISMI
            subgraph AUTONOMY_THINK_PHASE ["Think - Düşünme & Duygu Motoru"]
            AUTONOMY_T_TIME{"Uyku Saati mi?"}
            AUTONOMY_T_TIME -- Evet --> AUTONOMY_SLEEP_MODE[Düşük güç / Sakin nefes]
            AUTONOMY_T_TIME -- Hayır --> AUTONOMY_T_MOOD("mood.update Doğal Bozunma")
            
            AUTONOMY_T_MOOD --> AUTONOMY_T_SYNC[Baskın Duyguyu Seç<br>Örn: fear, joy, neutral]
            AUTONOMY_T_SYNC --> AUTONOMY_RANDOM_MICRO{Zar At: %40}
            AUTONOMY_RANDOM_MICRO -- Tutar --> AUTONOMY_DO_MICRO(Küçük Servo Titremesi<br>Canlılık Hissi)
            
            AUTONOMY_T_SYNC --> AUTONOMY_CHK_BORED{"Sıkılma Seviyesi<br>Yüksek mi?"}
            AUTONOMY_CHK_BORED -- Evet --> AUTONOMY_AGENTIC_CALL(AUTONOMY_LLM'e Karar Sor<br>Durum+Seçenekler)
            end
            
            AUTONOMY_THINK --> AUTONOMY_THINK_PHASE
            AUTONOMY_THINK_PHASE --> AUTONOMY_ACT[AUTONOMY_ACT: Konuşmaya Tepki Varsa]
            
            %% ACT KISMI (Konuşma Gelmişse)
            subgraph AUTONOMY_ACT_PHASE ["Act - Harekete Geçirme"]
            AUTONOMY_A_CHK_TXT{"Konuşma Metni<br>Dolu mu?"}
            AUTONOMY_A_CHK_TXT -- Hayır --> AUTONOMY_FINISH_LOOP((Tick Bitti))
            
            AUTONOMY_A_CHK_TXT -- Evet --> AUTONOMY_CHK_OWNER{"Sahip mi?"}
            AUTONOMY_CHK_OWNER -- Hayır / Kilitli --> AUTONOMY_REJECT[Erişim Reddedildi İşlemi] --> AUTONOMY_FINISH_LOOP
            
            AUTONOMY_CHK_OWNER -- Evet / Pas Geçildi --> AUTONOMY_USE_OLLAMA(Ollama Chat AUTONOMY_API Çağır)
            AUTONOMY_USE_OLLAMA --> AUTONOMY_RES_LLM(AUTONOMY_LLM Yanıtı: Text + Actions)
            
            AUTONOMY_RES_LLM --> AUTONOMY_PARSE_TAGS(AUTONOMY__apply_tags)
            
            AUTONOMY_PARSE_TAGS --> AUTONOMY_DO_OP[Donanım AUTONOMY_HTTP Çağrıları:<br>NeoPixel, AUTONOMY_TTS, Servo vb.] --> AUTONOMY_FINISH_LOOP
            end
            
            AUTONOMY_ACT --> AUTONOMY_ACT_PHASE
            AUTONOMY_FINISH_LOOP -->|time.sleep| AUTONOMY_START_LOOP
        end
        subgraph SG_CONFIG_CENTER ["CONFIG_CENTER Modülü"]
            direction TB
            %% Okuma Akışı
            CONFIG_CENTER_REQ_GET("GET /config") --> CONFIG_CENTER_READ_DISK("config.yml Oku")
            CONFIG_CENTER_READ_DISK --> CONFIG_CENTER_VALID_YAML{"YAML Geçerli mi?"}
            CONFIG_CENTER_VALID_YAML -- "Hayır" --> CONFIG_CENTER_LOAD_BACKUP("Backup Yükle")
            CONFIG_CENTER_VALID_YAML -- "Evet" --> CONFIG_CENTER_RET_CFG("JSON Olarak<br>Arayüze Dön")
            CONFIG_CENTER_LOAD_BACKUP --> CONFIG_CENTER_RET_CFG
            
            %% Yazma Akışı
            CONFIG_CENTER_REQ_POST("POST /config") --> CONFIG_CENTER_PARSE_NEW("Gelen JSON'ı Parse Et")
            CONFIG_CENTER_PARSE_NEW --> CONFIG_CENTER_VALID_SCHEMA{"Pydantic Şema<br>Doğrulaması?"}
            
            CONFIG_CENTER_VALID_SCHEMA -- "Hata" --> CONFIG_CENTER_RET_ERR("Hata Döndür:<br>Geçersiz Format")
            CONFIG_CENTER_VALID_SCHEMA -- "Başarılı" --> CONFIG_CENTER_SAVE_YAML("config.yml'e Yaz")
            
            CONFIG_CENTER_SAVE_YAML --> CONFIG_CENTER_RESTART_REQ{"Restart<br>Gerekiyor mu?"}
            CONFIG_CENTER_RESTART_REQ -- "Evet" --> CONFIG_CENTER_TRIG_RST("Modülü/Sistemi<br>Yeniden Başlat")
            CONFIG_CENTER_RESTART_REQ -- "Hayır" --> CONFIG_CENTER_HOT_RELOAD("Hafızadaki Objeyi<br>Güncelle (Hot-Reload)")
            
            CONFIG_CENTER_TRIG_RST --> CONFIG_CENTER_RET_OK("Başarılı")
            CONFIG_CENTER_HOT_RELOAD --> CONFIG_CENTER_RET_OK
        end
        subgraph SG_GATEWAY ["GATEWAY Modülü"]
            direction TB
            %% Başlangıç
            GATEWAY_START([GATEWAY_run_robot.py]) --> GATEWAY_INIT_LOG["init_logging_<br> Hata Yoksayılır"]
            GATEWAY_INIT_LOG --> GATEWAY_LOAD_CFG["load_config: <br> config.yml okuma"]
            GATEWAY_LOAD_CFG --> GATEWAY_CREATE_APP[GATEWAY_create_app]
            
            %% create_app iç akışı
            subgraph GATEWAY_create_app ["FastAPI Oluşturma"]
            GATEWAY_APP_INIT[FastAPI Uygulaması Başlat] --> GATEWAY_STATE_INIT[app.state.started empty]
            GATEWAY_STATE_INIT --> GATEWAY_CALL_BOOTSTRAP[bootstrap app, cfg]
            GATEWAY_CALL_BOOTSTRAP --> GATEWAY_CORE_API[Core GATEWAY_API /status mount]
            end
            
            GATEWAY_CREATE_APP --> GATEWAY_APP_INIT
            
            %% Bootstrap Akışı
            subgraph GATEWAY_Bootstrap ["Modül Yükleme Karar Ağacı"]
            GATEWAY_B_START([bootstrap başlar]) --> GATEWAY_READ_INC{"cfg.include var mı?"}
            GATEWAY_READ_INC -- Hayır --> GATEWAY_B_END([Döndür: started list])
            GATEWAY_READ_INC -- Evet --> GATEWAY_CHK_ARDUINO{"include.arduino == true?"}
            
            %% Arduino
            GATEWAY_CHK_ARDUINO -- Evet --> GATEWAY_TRY_ARD[arduino.GATEWAY__include_arduino]
            GATEWAY_TRY_ARD --> GATEWAY_CATCH_ARD{"Hata var mı?"}
            GATEWAY_CATCH_ARD -- Evet --> GATEWAY_LOG_ARD[warning: module failed] --> GATEWAY_CHK_VIS
            GATEWAY_CATCH_ARD -- Hayır --> GATEWAY_ADD_ARD[started arduino True] --> GATEWAY_CHK_VIS
            GATEWAY_CHK_ARDUINO -- Hayır --> GATEWAY_CHK_VIS{"include.vlm_bridge == true?"}
            
            %% VLM Bridge
            GATEWAY_CHK_VIS -- Evet --> GATEWAY_TRY_VIS[vlm.GATEWAY__include_vlm_bridge]
            GATEWAY_TRY_VIS --> GATEWAY_CATCH_VIS{"Hata var mı?"}
            GATEWAY_CATCH_VIS -- Evet --> GATEWAY_LOG_VIS[warning: module failed] --> GATEWAY_CHK_AUTO
            GATEWAY_CATCH_VIS -- Hayır --> GATEWAY_ADD_VIS[started GATEWAY_vlm_bridge True] --> GATEWAY_CHK_AUTO
            GATEWAY_CHK_VIS -- Hayır --> GATEWAY_CHK_AUTO{"include.autonomy == true?"}
            
            %% Autonomy (Diğerleri benzer mantıkta olduğu için temsilidir)
            GATEWAY_CHK_AUTO -- Evet --> GATEWAY_TRY_AUTO[autonomy.GATEWAY__include_autonomy]
            GATEWAY_TRY_AUTO --> GATEWAY_CATCH_AUTO{"Hata var mı?"}
            GATEWAY_CATCH_AUTO -- Evet --> GATEWAY_LOG_AUTO[warning: module failed] --> GATEWAY_CHK_OTHER
            GATEWAY_CATCH_AUTO -- Hayır --> GATEWAY_ADD_AUTO[started autonomy ServiceClient] --> GATEWAY_CHK_OTHER
            GATEWAY_CHK_AUTO -- Hayır --> GATEWAY_CHK_OTHER{"Diğer 20+ Modül <br> neopixel, speak, vb."}
            
            %% Diğerleri
            GATEWAY_CHK_OTHER --> GATEWAY_B_END
            end
            
            GATEWAY_CALL_BOOTSTRAP --> GATEWAY_B_START
            GATEWAY_B_END --> GATEWAY_CORE_API
            GATEWAY_CORE_API --> GATEWAY_RUN_UVICORN([uvicorn.run host:port])
        end
        subgraph SG_INTERACTIONS ["INTERACTIONS Modülü"]
            direction TB
            INTERACTIONS_START((Tick Timer <br> Her 1 saniye)) --> INTERACTIONS_GATHER_METRICS
            
            %% Metrik Toplama
            subgraph INTERACTIONS_SENSE_METRICS ["Metrik Toplama MetricsCollector"]
            INTERACTIONS_GATHER_METRICS[Sistem Verilerini Oku] --> INTERACTIONS_CPU_T(INTERACTIONS_CPU Sıcaklık)
            INTERACTIONS_GATHER_METRICS --> INTERACTIONS_CPU_L(INTERACTIONS_CPU Yük %si)
            INTERACTIONS_GATHER_METRICS --> INTERACTIONS_NET_T(Ağ Trafiği / Burst)
            INTERACTIONS_GATHER_METRICS --> INTERACTIONS_ARDU_C{Arduino <br>Heartbeat<br>Aktif mi?}
            
            INTERACTIONS_ARDU_C -- Evet --> INTERACTIONS_ARDU_OK[Arduino Alive]
            INTERACTIONS_ARDU_C -- Hayır --> INTERACTIONS_ARDU_ERR[Arduino Dead]
            
            INTERACTIONS_CPU_T --> INTERACTIONS_MERGE_M
            INTERACTIONS_CPU_L --> INTERACTIONS_MERGE_M
            INTERACTIONS_NET_T --> INTERACTIONS_MERGE_M
            INTERACTIONS_ARDU_OK --> INTERACTIONS_MERGE_M
            INTERACTIONS_ARDU_ERR --> INTERACTIONS_MERGE_M
            INTERACTIONS_MERGE_M[Tam Metrik Sözlüğü]
            end
            
            INTERACTIONS_MERGE_M --> INTERACTIONS_READ_EVENTS
            
            %% Olay Toplama
            subgraph INTERACTIONS_READ_EVENTS_Q ["Olay Kuyruğunu Oku"]
            INTERACTIONS_READ_EVENTS[INTERACTIONS_API /event Kuyruğunu Çek] --> INTERACTIONS_HAS_EVT{Kuyrukta Olay<br>Var mı?}
            INTERACTIONS_HAS_EVT -- Evet --> INTERACTIONS_POP_EVT(Olayları Metrik <br> Sözlüğüne Ekle)
            INTERACTIONS_HAS_EVT -- Hayır --> INTERACTIONS_KEEP_VAR(Sadece Metrikler)
            INTERACTIONS_POP_EVT --> INTERACTIONS_CONTEXT_DICT
            INTERACTIONS_KEEP_VAR --> INTERACTIONS_CONTEXT_DICT
            end
            
            INTERACTIONS_CONTEXT_DICT --> INTERACTIONS_EVAL_RULES
            
            %% Kural Değerlendirme Döngüsü
            subgraph INTERACTIONS_RULE_EVALUATION ["Kural Değerlendirme Motoru"]
            INTERACTIONS_EVAL_RULES[Tüm Kuralları Sırayla Kontrol Et]
            
            INTERACTIONS_EVAL_RULES --> INTERACTIONS_RULE_1{Kural 1: <br> if arduino == dead?}
            INTERACTIONS_RULE_1 -- Evet (Öncelik 100) --> INTERACTIONS_ACT_ERR[Kırmızı Renk, <br> breathe Animasyonu]
            
            INTERACTIONS_RULE_1 -- Hayır --> INTERACTIONS_RULE_2{Kural 2: <br> if INTERACTIONS_cpu_temp > 85?}
            INTERACTIONS_RULE_2 -- Evet (Öncelik 90) --> INTERACTIONS_ACT_HOT[Turuncu Renk, <br> pulse Animasyonu]
            
            INTERACTIONS_RULE_2 -- Hayır --> INTERACTIONS_RULE_3{Kural 3: <br> if event == autonomy.greet?}
            INTERACTIONS_RULE_3 -- Evet (Öncelik 80) --> INTERACTIONS_ACT_GREET[Yeşil Renk, <br> wave Animasyonu]
            
            INTERACTIONS_RULE_3 -- Hayır --> INTERACTIONS_RULE_N{Kural N...}
            INTERACTIONS_RULE_N -- Hiçbiri Uymadıysa --> INTERACTIONS_ACT_DEF[Varsayılan Taban Animasyonu: INTERACTIONS_BREATHE]
            
            INTERACTIONS_ACT_ERR --> INTERACTIONS_SEND_NEO
            INTERACTIONS_ACT_HOT --> INTERACTIONS_SEND_NEO
            INTERACTIONS_ACT_GREET --> INTERACTIONS_SEND_NEO
            INTERACTIONS_ACT_DEF --> INTERACTIONS_SEND_NEO
            end
            
            INTERACTIONS_SEND_NEO(NeoHttpClient) --> INTERACTIONS_HTTP_REQ([INTERACTIONS_HTTP INTERACTIONS_POST /neopixel/animate])
        end
        subgraph SG_STATE_MANAGER ["STATE_MANAGER Modülü"]
            direction TB
            %% Veri Yazma (SET)
            subgraph Update Flow [Durum Güncelleme İşlemi STATE_MANAGER_POST]
            STATE_MANAGER_REQ_UPDATE([STATE_MANAGER_POST /set/emotions <br> veya /set/battery]) --> STATE_MANAGER_PARSE_PAYLOAD(STATE_MANAGER_JSON Body Al)
            
            STATE_MANAGER_PARSE_PAYLOAD --> STATE_MANAGER_VALIDATE_PAYLOAD{"Anahtarlar <br> Geçerli mi?"}
            
            STATE_MANAGER_VALIDATE_PAYLOAD -- Hayır --> STATE_MANAGER_RET_ERR_U([Hata Döndür])
            STATE_MANAGER_VALIDATE_PAYLOAD -- Evet --> STATE_MANAGER_MUTEX_LOCK(Kilit Al - Thread Safe)
            
            STATE_MANAGER_MUTEX_LOCK --> STATE_MANAGER_MERGE_DICT[Store İçindeki Dictionary'e <br> Yeni Veriyi Merge Et] --> STATE_MANAGER_MUTEX_REL(Kilidi Bırak)
            
            STATE_MANAGER_MUTEX_REL --> STATE_MANAGER_TRIG_PUB_SUB{"Değişim Bildirimi <br> Aboneleri Var mı?"}
            STATE_MANAGER_TRIG_PUB_SUB -- Evet --> STATE_MANAGER_NOTIFY_SUBS(Abonelere Event Pushing) --> STATE_MANAGER_RET_OK_U([Başarılı])
            STATE_MANAGER_TRIG_PUB_SUB -- Hayır --> STATE_MANAGER_RET_OK_U
            end
            
            %% Veri Okuma (GET)
            subgraph Read Flow [Durum Okuma İşlemi STATE_MANAGER_GET]
            STATE_MANAGER_REQ_READ([STATE_MANAGER_GET /get/emotions <br> veya /state]) --> STATE_MANAGER_PARSE_QRY(Query Parametresi Al <br> Varsa Sadece Onu Ver)
            
            STATE_MANAGER_PARSE_QRY --> STATE_MANAGER_GET_LOCK[Kilit Al] --> STATE_MANAGER_CLONE_DAT[Kopya Oluştur <br> copy.deepcopy] --> STATE_MANAGER_UNLOCK[Kilidi Bırak]
            
            STATE_MANAGER_UNLOCK --> STATE_MANAGER_RET_JSON([Seçili State STATE_MANAGER_JSON'ı Dön])
            end
        end
    end
    subgraph LAYER_AI ["3. YAPAY ZEKA VE RAG"]
        direction TB
        subgraph SG_OLLAMA ["OLLAMA Modülü"]
            direction TB
            %% Ana Çağrı
            OLLAMA_API_IN([OLLAMA_POST /chat]) --> OLLAMA_CHAT_MET[OllamaChatService.chat text, OLLAMA_apply_actions]
            
            OLLAMA_CHAT_MET --> OLLAMA_GET_PERSONA[PersonaProvider.OLLAMA_system_prompt name]
            OLLAMA_GET_PERSONA --> OLLAMA_CHK_PERSONA{Kişilik var mı?}
            
            OLLAMA_CHK_PERSONA -- Hayır --> OLLAMA_DEF_PERSONA[Varsayılan sentry seç]
            OLLAMA_CHK_PERSONA -- Evet --> OLLAMA_USE_PERSONA[Kişilik sistem metni al]
            
            OLLAMA_USE_PERSONA --> OLLAMA_GET_HIST[ChatMemory.OLLAMA_get_context]
            OLLAMA_DEF_PERSONA --> OLLAMA_GET_HIST
            
            OLLAMA_GET_HIST --> OLLAMA_BLD_PROMPT{Mesajları Birleştir <br> System + History + User}
            
            OLLAMA_BLD_PROMPT --> OLLAMA_OLLAMA_API(OllamaClient.OLLAMA_generate_json)
            
            %% Ollama API Yanıt Döngüsü
            subgraph OLLAMA_Ollama_API ["LLM İstek İşlemi"]
            OLLAMA_REQ[LLMe OLLAMA_HTTP OLLAMA_POST <br> format: json] --> OLLAMA_RESP{OLLAMA_HTTP 200 mü?}
            OLLAMA_RESP -- Hayır --> OLLAMA_ERR_RET([error: Failed to reach OLLAMA_LLM])
            OLLAMA_RESP -- Evet --> OLLAMA_RAW_JSON(Yanıt Metni Al)
            end
            
            OLLAMA_OLLAMA_API --> OLLAMA_REQ
            OLLAMA_RAW_JSON --> OLLAMA_PARSE_JSON_P{Pydantic Modelle<br>OLLAMA_JSON Parse Et}
            
            %% JSON Ayrıştırma Mantığı
            subgraph OLLAMA_Parse_Logic ["Çıktı Ayrıştırma if/else"]
            OLLAMA_PARSE_JSON_P -- Başarılı (Valid OLLAMA_JSON) --> OLLAMA_P_SUCCESS[text, thoughts, actions<br>değişkenlerini ata]
            OLLAMA_PARSE_JSON_P -- Başarısız (Syntax Error) --> OLLAMA_EXTRACT_TAGS[OLLAMA_extract_llm_tags OLLAMA_raw_text <br> Regex ile OLLAMA_XML tagleri ara]
            
            OLLAMA_EXTRACT_TAGS --> OLLAMA_TAGS_RES[actions array oluştur]
            
            OLLAMA_P_SUCCESS --> OLLAMA_APPLY_ACT
            OLLAMA_TAGS_RES --> OLLAMA_APPLY_ACT
            end
            
            %% Etkileşim Kararı
            OLLAMA_APPLY_ACT{OLLAMA_apply_actions=True?}
            OLLAMA_APPLY_ACT -- Hayır --> OLLAMA_SAVE_MEM(ChatMemory.OLLAMA_add_interaction)
            OLLAMA_APPLY_ACT -- Evet --> OLLAMA_HTTP_POST_BRAIN(OLLAMA_POST /autonomy/OLLAMA_apply_actions)
            
            OLLAMA_SAVE_MEM --> OLLAMA_RET_FINAL([OLLAMA_API Yanıtı Döndür])
            OLLAMA_HTTP_POST_BRAIN --> OLLAMA_SAVE_MEM
        end
    end
    subgraph LAYER_ACT ["4. FIZIKSEL EYLEM VE TEPKI"]
        direction TB
        subgraph SG_ANIMATE ["ANIMATE Modülü"]
            direction TB
            %% Ana Giriş
            ANIMATE_API_REQ([ANIMATE_POST /animate/run]) --> ANIMATE_PARSE_REQ(Parametreler: <br> name, speed, loop)
            
            ANIMATE_PARSE_REQ --> ANIMATE_CHK_NAME{"Animasyon<br>adı geçerli mi?"}
            
            %% Dosya Yükleme Kararları
            subgraph Loading Logic [ANIMATE_YAML Yükleme ve Doğrulama]
            ANIMATE_CHK_NAME -- Hayır --> ANIMATE_RET_ERR([Hata: name gerekli])
            ANIMATE_CHK_NAME -- Evet --> ANIMATE_CHK_YAML(Dosyayı Oku: <br> animations/name.yml)
            
            ANIMATE_CHK_YAML --> ANIMATE_IS_EXIST{"Dosya Var mı?"}
            ANIMATE_IS_EXIST -- Hayır --> ANIMATE_RET_NF([Hata: Animasyon Bulunamadı])
            
            ANIMATE_IS_EXIST -- Evet --> ANIMATE_PARSE_YAML{"YAML formatı<br>doğru mu? (steps listesi)"}
            ANIMATE_PARSE_YAML -- Hayır --> ANIMATE_RET_INV([Hata: Geçersiz Format])
            end
            
            %% Oynatma Motoru (Sequencer)
            subgraph Engine Loop [Oynatma Motoru / Sequencer Döngüsü]
            ANIMATE_PARSE_YAML -- Evet --> ANIMATE_EXTRACT_STEPS(Tüm 'steps' listesini al)
            
            ANIMATE_EXTRACT_STEPS --> ANIMATE_LOOP_STEP[Döngü: Her step için]
            ANIMATE_LOOP_STEP --> ANIMATE_CALC_DUR(Hesapla: <br> duration = step.ANIMATE_duration_ms / speed)
            
            ANIMATE_CALC_DUR --> ANIMATE_CHK_POSE{"Pose Verisi <br> Var mı?"}
            
            ANIMATE_CHK_POSE -- Evet --> ANIMATE_ACT_SRV(Arduino Serial:<br> 'ANIMATE_set_pose' komutu gönder) --> ANIMATE_ACT_WAIT(Bekle: 1 veya hesaplanan <br> süre kadar delay)
            ANIMATE_CHK_POSE -- Hayır --> ANIMATE_ACT_WAIT
            
            ANIMATE_ACT_WAIT --> ANIMATE_NEXT_STEP{"Bitti mi?"}
            ANIMATE_NEXT_STEP -- Hayır --> ANIMATE_LOOP_STEP
            end
            
            ANIMATE_NEXT_STEP -- Evet --> ANIMATE_CHK_LOOP{"Loop = True mu?"}
            ANIMATE_CHK_LOOP -- Evet --> ANIMATE_EXTRACT_STEPS
            ANIMATE_CHK_LOOP -- Hayır --> ANIMATE_RET_OK([ok: true])
        end
        subgraph SG_ARDUINO_SERIAL ["ARDUINO_SERIAL Modülü"]
            direction TB
            %% Başlatma Mantığı
            ARDUINO_SERIAL_START([start]) --> ARDUINO_SERIAL_CHK_THREAD{"Okuma Thread'i <br> çalışıyor mu?"}
            ARDUINO_SERIAL_CHK_THREAD -- Evet --> ARDUINO_SERIAL_IGNORE([Hiçbir Şey Yapma])
            ARDUINO_SERIAL_CHK_THREAD -- Hayır --> ARDUINO_SERIAL_FIND_PORT(Seri Portu Bul <br> ARDUINO_SERIAL__autodetect_port)
            
            ARDUINO_SERIAL_FIND_PORT --> ARDUINO_SERIAL_CHK_PORT{"Port Bulundu mu?"}
            ARDUINO_SERIAL_CHK_PORT -- Hayır --> ARDUINO_SERIAL_ERR_START([ARDUINO_SERIAL_HATA: Port Yok veya Erişilemez])
            ARDUINO_SERIAL_CHK_PORT -- Evet --> ARDUINO_SERIAL_OPEN_SERIAL(SerialTransport Başlat)
            
            ARDUINO_SERIAL_OPEN_SERIAL --> ARDUINO_SERIAL_CREATE_THREADS(Send ve Read <br> Queue Oluştur)
            ARDUINO_SERIAL_CREATE_THREADS --> ARDUINO_SERIAL_RUN_THREAD[Arka Plan ARDUINO_SERIAL__read_loop Oku]
            
            %% Arka Plan Okuma Döngüsü (Read Loop)
            subgraph ARDUINO_SERIAL_ReadLoop ["Arka Plan Okuma Akışı"]
            ARDUINO_SERIAL_LOOP_START((Döngü Başı)) --> ARDUINO_SERIAL_READ_LINE{"Seri Porttan<br>Satır Oku"}
            ARDUINO_SERIAL_READ_LINE -- Boş / Timeout --> ARDUINO_SERIAL_LOOP_START
            ARDUINO_SERIAL_READ_LINE -- Veri Var --> ARDUINO_SERIAL_PARSE_JSON{"JSON Parse <br> Başarılı mı?"}
            ARDUINO_SERIAL_PARSE_JSON -- Hayır --> ARDUINO_SERIAL_LOG_ERR[Hata Logla] --> ARDUINO_SERIAL_LOOP_START
            ARDUINO_SERIAL_PARSE_JSON -- Evet --> ARDUINO_SERIAL_INGEST(ARDUINO_SERIAL_JSON Verisini İşle <br> ARDUINO_SERIAL__ingest_message)
            
            ARDUINO_SERIAL_INGEST --> ARDUINO_SERIAL_CHK_TYPE{Gelen Mesaj Türü}
            
            ARDUINO_SERIAL_CHK_TYPE -- ARDUINO_SERIAL_RFID Olayı --> ARDUINO_SERIAL_EVENT_RFID[ARDUINO_SERIAL_RFID Handler <br> ARDUINO_SERIAL__record_rfid / Webhook] --> ARDUINO_SERIAL_LOOP_START
            ARDUINO_SERIAL_CHK_TYPE -- Telemetri --> ARDUINO_SERIAL_EVENT_TLM[Telemetri Handler <br> Global Durum] --> ARDUINO_SERIAL_LOOP_START
            ARDUINO_SERIAL_CHK_TYPE -- Yanıt (ok / error) --> ARDUINO_SERIAL_QUEUE_PUSH[Uygulama Yanıt<br>Kuyruğuna Koy] --> ARDUINO_SERIAL_LOOP_START
            end
            
            ARDUINO_SERIAL_RUN_THREAD --> ARDUINO_SERIAL_LOOP_START
            
            %% Komut Gönderme Akışı
            subgraph ARDUINO_SERIAL_WriteCycle ["Komut Gönderme - send/request"]
            ARDUINO_SERIAL_API_CALL([ARDUINO_SERIAL_request_cmd]) --> ARDUINO_SERIAL_MAKE_JSON(ARDUINO_SERIAL_JSON'a Çevir + <br> Satır Sonu Ekle)
            ARDUINO_SERIAL_MAKE_JSON --> ARDUINO_SERIAL_CHK_ALIVE{"Bağlantı Açık mı?"}
            ARDUINO_SERIAL_CHK_ALIVE -- Hayır --> ARDUINO_SERIAL_RET_NONE([None Döndür])
            ARDUINO_SERIAL_CHK_ALIVE -- Evet --> ARDUINO_SERIAL_WRITE(Serial Write)
            ARDUINO_SERIAL_WRITE --> ARDUINO_SERIAL_WAIT_Q{"Okuma Kuyruğunda<br>Yanıt Bekle - Timeout"}
            ARDUINO_SERIAL_WAIT_Q -- Timeout --> ARDUINO_SERIAL_RET_ERR([Hata Formatı Döndür])
            ARDUINO_SERIAL_WAIT_Q -- Yanıt Geldi --> ARDUINO_SERIAL_RET_RESP([Yanıtı Döndür])
            end
        end
        subgraph SG_NEOPIXEL ["NEOPIXEL Modülü"]
            direction TB
            %% Ana Giriş
            NEOPIXEL_API_REQ([NEOPIXEL_HTTP NEOPIXEL_POST /animate]) --> NEOPIXEL_PARSE_REQ(Gelen parametreler: <br> name, emotions, r, g, b, speed, loop)
            
            NEOPIXEL_PARSE_REQ --> NEOPIXEL_CHK_NAME{"Animasyon<br>Adı Var mı?"}
            
            %% Animasyon Yürütme Döngüsü
            subgraph Animation Pipeline [Animasyon Yürütme ve Renk Seçimi]
            
            NEOPIXEL_CHK_NAME -- Hayır --> NEOPIXEL_RET_ERR([Hata: name gerekli])
            NEOPIXEL_CHK_NAME -- Evet --> NEOPIXEL_CHK_COLOR{"r,g,b<br>verilmiş mi?"}
            
            %% Renk Belirleme Karar Ağacı
            NEOPIXEL_CHK_COLOR -- Evet --> NEOPIXEL_SET_RGB[r,g,b Kullan]
            NEOPIXEL_CHK_COLOR -- Hayır --> NEOPIXEL_CHK_EMOTION{"Emotions Listesi<br>Verilmiş mi?"}
            
            NEOPIXEL_CHK_EMOTION -- Evet --> NEOPIXEL_LOOP_EMO[Duyguları Sırayla Kontrol Et: <br> joy, curiosity...]
            NEOPIXEL_LOOP_EMO --> NEOPIXEL_FETCH_YML[EmotionStore'dan <br> emotion.yml Yükle]
            NEOPIXEL_FETCH_YML --> NEOPIXEL_CHK_YML{"Dosya ve Renk<br>Var mı?"}
            
            NEOPIXEL_CHK_YML -- Evet --> NEOPIXEL_RAND_PICK(Listeden Rastgele<br>Renk Seç) --> NEOPIXEL_SET_RGB
            NEOPIXEL_CHK_YML -- Hayır --> NEOPIXEL_LOOP_EMO
            
            NEOPIXEL_CHK_EMOTION -- Hayır --> NEOPIXEL_SET_DEF[Varsayılan: Beyaz <br> r=255, g=255, b=255] --> NEOPIXEL_SET_RGB
            
            %% Animasyon Tetikleme
            NEOPIXEL_SET_RGB --> NEOPIXEL_RUNNER_CALL(NeoRunner.animate)
            NEOPIXEL_RUNNER_CALL --> NEOPIXEL_DRIVER_CALL(NeoDriver.animate)
            
            %% Sürücü Karar Aşaması
            NEOPIXEL_DRIVER_CALL --> NEOPIXEL_CHK_HW{"Pi5Neo SPI<br>Erişilebilir mi?"}
            NEOPIXEL_CHK_HW -- Evet --> NEOPIXEL_HW_RUN(Donanım Hızlandırmalı<br>Sürücü - C modülü)
            NEOPIXEL_CHK_HW -- Hayır --> NEOPIXEL_SIM_RUN(NEOPIXEL__SimStrip - Geliştirici<br>Simülatörü Buffer'ı)
            end
            
            NEOPIXEL_HW_RUN --> NEOPIXEL_RET_OK([ok: true])
            NEOPIXEL_SIM_RUN --> NEOPIXEL_RET_OK
        end
        subgraph SG_PISERVO ["PISERVO Modülü"]
            direction TB
            %% PiServo Akışı
            PISERVO_REQ_SRV("POST /piservo/set") --> PISERVO_PARSE_ID("Hangi Kulak?<br>Sol (12) / Sağ (13)")
            
            PISERVO_PARSE_ID --> PISERVO_CHK_LIB{"RPi.GPIO<br>Kurulu mu?"}
            
            PISERVO_CHK_LIB -- "Hayır (PC/Mac)" --> PISERVO_LOG_MOCK("Uyarı: RPi.GPIO Yok<br>Yazılımsal Simülasyon (Mock)")
            PISERVO_CHK_LIB -- "Evet" --> PISERVO_SET_DUTY("Açı (0-180) -> Duty Cycle (%)<br>Dönüştür")
            
            PISERVO_SET_DUTY --> PISERVO_APLY_PWM("pwm.ChangeDutyCycle(val)")
            PISERVO_LOG_MOCK --> PISERVO_APLY_PWM
            
            PISERVO_APLY_PWM --> PISERVO_RET_OK("Başarılı")
        end
        subgraph SG_SPEAK ["SPEAK Modülü"]
            direction TB
            %% Ana Giriş
            SPEAK_API_REQ([SPEAK_POST /speak/say]) --> SPEAK_PARSE_REQ(Gelen parametreler: <br> text, tone, engine)
            
            SPEAK_PARSE_REQ --> SPEAK_CHK_TEXT{"Metin/Text <br> Boş mu?"}
            
            %% API Kontrolleri
            subgraph SPEAK_TTS Request Validation [İstek Doğrulama & Temizlik]
            SPEAK_CHK_TEXT -- Evet --> SPEAK_RET_ERR([Hata: Text Gerekli])
            SPEAK_CHK_TEXT -- Hayır --> SPEAK_CLEAN_TEXT(Regex ile Markdown <br> ve SPEAK_JSON Artıklarını Temizle)
            SPEAK_CLEAN_TEXT --> SPEAK_CHK_ENGINE{"Hangi Motor?"}
            end
            
            %% Motor Seçimi
            subgraph Engine Selection [SPEAK_TTS Motoru Seçimi]
            SPEAK_CHK_ENGINE -- Default / pyttsx3 --> SPEAK_ENGINE_PYTTS(pyttsx3)
            SPEAK_CHK_ENGINE -- Piper --> SPEAK_ENGINE_PIPER(Piper / Offline Türkçe)
            SPEAK_CHK_ENGINE -- Diğer (espeak, vb.) --> SPEAK_ENGINE_DEF(Fallback Engine)
            end
            
            SPEAK_ENGINE_PYTTS --> SPEAK_APPLY_TONE
            SPEAK_ENGINE_PIPER --> SPEAK_APPLY_TONE
            SPEAK_ENGINE_DEF --> SPEAK_APPLY_TONE
            
            %% Duygusal Tonlama ve Sentezleme
            subgraph Tone Application [Duygu / Ton Ayarlama]
            SPEAK_APPLY_TONE --> SPEAK_CHK_TONE{"Tone Değeri: <br> 'happy', 'sad', 'angry' ..."}
            
            SPEAK_CHK_TONE -- happy --> SPEAK_SET_H[Hız: +%20, Ses: +%10] --> SPEAK_SYNTHESIZE
            SPEAK_CHK_TONE -- sad --> SPEAK_SET_S[Hız: -%25, Ses: -%20] --> SPEAK_SYNTHESIZE
            SPEAK_CHK_TONE -- angry --> SPEAK_SET_A[Hız: +%10, Ses: SPEAK_MAX] --> SPEAK_SYNTHESIZE
            SPEAK_CHK_TONE -- neutral / Yok --> SPEAK_SET_N[Normal Hız ve Ses] --> SPEAK_SYNTHESIZE
            
            SPEAK_SYNTHESIZE(SPEAK_TTS Sentezleme ve <br> SPEAK_ALSA / aplay ile Oynatma)
            end
            
            SPEAK_SYNTHESIZE --> SPEAK_DONE([ok: true])
        end
    end
    subgraph LAYER_BG ["5. ARKA PLAN SERVISLERI"]
        direction TB
        subgraph SG_CALIBRATION ["CALIBRATION Modülü"]
            direction TB
            %% Kalibrasyon Modu Başlatma
            CALIBRATION_START(Kalibrasyon Modu İsteği) --> CALIBRATION_GET_REQ(CALIBRATION_POST /calibration/start)
            
            CALIBRATION_GET_REQ --> CALIBRATION_CHK_STATE{Robot Hareket<br>Halinde mi?}
            
            CALIBRATION_CHK_STATE -- Evet --> CALIBRATION_RET_BUSY(Hata: Önce robotu durdurun)
            CALIBRATION_CHK_STATE -- Hayır --> CALIBRATION_SET_STATE(Mod = CALIBRATION_CALIBRATION_MODE)
            
            %% Çekirdek Döngü
            subgraph Kalibrasyon Döngüsü
            CALIBRATION_SET_STATE --> CALIBRATION_RECV_CMD(İstemciden Servo Açısı Al Örn: pan: 95)
            CALIBRATION_RECV_CMD --> CALIBRATION_SEND_ARDU(Arduinoya Doğrudan İlet: CALIBRATION_set_servo id value)
            CALIBRATION_SEND_ARDU --> CALIBRATION_WAIT_USR{Kullanıcı Onayı?}
            
            CALIBRATION_WAIT_USR -- Hayır (Değiştir) --> CALIBRATION_RECV_CMD
            CALIBRATION_WAIT_USR -- Evet (Kaydet) --> CALIBRATION_SAVE_CONF
            end
            
            %% Kaydetme Döngüsü
            subgraph Kalıcı Hafıza
            CALIBRATION_SAVE_CONF(Yapılandırmayı Yaz) --> CALIBRATION_CHK_DEST{Hedef Neresi?}
            
            CALIBRATION_CHK_DEST -- CALIBRATION_EEPROM --> CALIBRATION_SEND_EEP(Arduino CALIBRATION_EEPROM<br>Write Komutu)
            CALIBRATION_CHK_DEST -- Raspberry Pi --> CALIBRATION_WRITE_JSON(config.yml / calib.json<br>Üzerine Yaz)
            end
            
            CALIBRATION_SEND_EEP --> CALIBRATION_RET_OK(Başarılı)
            CALIBRATION_WRITE_JSON --> CALIBRATION_RET_OK
        end
        subgraph SG_DIAGNOSTICS ["DIAGNOSTICS Modülü"]
            direction TB
            %% Test Akışı
            DIAGNOSTICS_START("self_test Başlar") --> DIAGNOSTICS_CHK_ARDU{"Arduino<br>Ping"}
            DIAGNOSTICS_CHK_ARDU -- "Timeout" --> DIAGNOSTICS_FAIL_ARDU("Hata:<br>Arduino Bağlantısı Koptu")
            DIAGNOSTICS_CHK_ARDU -- "OK" --> DIAGNOSTICS_CHK_CAM{"Kamera<br>Cevap"}
            
            DIAGNOSTICS_CHK_CAM -- "Hata" --> DIAGNOSTICS_FAIL_CAM("Uyarı:<br>Kamera Bulunamadı")
            DIAGNOSTICS_CHK_CAM -- "OK" --> DIAGNOSTICS_CHK_LLM{"Ollama<br>Servisi"}
            
            DIAGNOSTICS_CHK_LLM -- "Kapalı" --> DIAGNOSTICS_FAIL_LLM("Uyarı:<br>Ollama Yok, Offline Mod")
            DIAGNOSTICS_CHK_LLM -- "OK" --> DIAGNOSTICS_FINISH_TEST
            
            DIAGNOSTICS_FAIL_ARDU --> DIAGNOSTICS_AGGREGATE
            DIAGNOSTICS_FAIL_CAM --> DIAGNOSTICS_AGGREGATE
            DIAGNOSTICS_FAIL_LLM --> DIAGNOSTICS_AGGREGATE
            DIAGNOSTICS_FINISH_TEST --> DIAGNOSTICS_AGGREGATE
            
            DIAGNOSTICS_AGGREGATE("Tüm Test Sonuçlarını<br>JSON Olarak Topla") --> DIAGNOSTICS_CHK_CRIT{"Kritik Hata Var mı?"}
            
            DIAGNOSTICS_CHK_CRIT -- "Evet (Örn: Arduino)" --> DIAGNOSTICS_PLAY_ERR("Speak TTS ile 'Kritik sistem hatası' Sentezle<br>NeoPixel KIRMIZI")
            DIAGNOSTICS_CHK_CRIT -- "Hayır" --> DIAGNOSTICS_PLAY_OK("Tüm sistemler çevrimiçi<br>NeoPixel YEŞİL")
        end
        subgraph SG_LOGWRAPPER ["LOGWRAPPER Modülü"]
            direction TB
            %% Log Yakalama Akışı
            LOGWRAPPER_G_LOG("Herhangi Bir Modülde<br>logger.error/info") --> LOGWRAPPER_CATCH_HND("WebSocketLogHandler<br>Yakalar (Intercept)")
            
            LOGWRAPPER_CATCH_HND --> LOGWRAPPER_FMT_JSON("Zaman, Modül Adı, Renk<br>Bilgilerini JSON Yap")
            
            LOGWRAPPER_FMT_JSON --> LOGWRAPPER_WS_BCAST("Tüm Aktif WebSocket<br>İstemcilerine Yolla")
            
            %% WS İstekleri
            LOGWRAPPER_FRONTEND("Web Arayüzü<br>(Admin Panel)") --> LOGWRAPPER_REQ_WS("WS /logs/stream")
            LOGWRAPPER_REQ_WS --> LOGWRAPPER_ADD_CLIENT("İstemciyi Aktif Listeye<br>(clients_set) Ekle")
            LOGWRAPPER_ADD_CLIENT --> LOGWRAPPER_WAIT_LOGS("Log Bekleme Döngüsü")
            LOGWRAPPER_WS_BCAST --> LOGWRAPPER_WAIT_LOGS
        end
        subgraph SG_MUTAGEN ["MUTAGEN Modülü"]
            direction TB
            %% Sync Akışı
            MUTAGEN_START("Özel Geliştirici Scripti<br>(Örn: sync.bat)") --> MUTAGEN_CHK_MTG{"mutagen<br>kurulu mu?"}
            
            MUTAGEN_CHK_MTG -- "Hayır" --> MUTAGEN_ERR_MTG("Hata:<br>Mutagen CLI Bulunamadı")
            MUTAGEN_CHK_MTG -- "Evet" --> MUTAGEN_CREATE_SESSION("mutagen sync create<br>--name=sentrybot<br>./ -> pi@10.x.x.x:~/SentryBOT")
            
            MUTAGEN_CREATE_SESSION --> MUTAGEN_CHK_SESS{"Session Başarılı<br>Kuruldu mu?"}
            
            MUTAGEN_CHK_SESS -- "Hayır" --> MUTAGEN_ERR_SSH("Hata:<br>SSH Şifresi veya Host Yanlış")
            MUTAGEN_CHK_SESS -- "Evet" --> MUTAGEN_MON_SESS("mutagen sync monitor<br>sentrybot")
            
            %% Durum Yönetimi
            MUTAGEN_MON_SESS --> MUTAGEN_RUNNING("Sürekli Senkronizasyon<br>(İki yönlü + Ignore Listesi)")
        end
        subgraph SG_NOTIFIER ["NOTIFIER Modülü"]
            direction TB
            %% İstek Gelmesi
            NOTIFIER_EVT_TRIG("Herhangi Bir Modül:<br>POST /notify/send") --> NOTIFIER_PARSE_MSG("Parametre: title, message, level")
            
            NOTIFIER_PARSE_MSG --> NOTIFIER_CHK_LVL{"Level (Seviye)<br>Ne?"}
            
            NOTIFIER_CHK_LVL -- "INFO" --> NOTIFIER_SET_ICON("ℹ️ İkonu Ekle")
            NOTIFIER_CHK_LVL -- "WARNING" --> NOTIFIER_SET_ICON_W("⚠️ İkonu Ekle")
            NOTIFIER_CHK_LVL -- "CRITICAL" --> NOTIFIER_SET_ICON_C("🚨 İkonu Ekle")
            
            NOTIFIER_SET_ICON --> NOTIFIER_CHK_TEL{"Telegram Token<br>Tanımlı mı?"}
            NOTIFIER_SET_ICON_W --> NOTIFIER_CHK_TEL
            NOTIFIER_SET_ICON_C --> NOTIFIER_CHK_TEL
            
            %% API Gönderimi
            NOTIFIER_CHK_TEL -- "Evet" --> NOTIFIER_REQ_TEL("Telegram API'ye Req At<br>(SendMessage)")
            NOTIFIER_CHK_TEL -- "Hayır" --> NOTIFIER_CHK_DIS{"Discord Webhook<br>Var mı?"}
            
            NOTIFIER_REQ_TEL --> NOTIFIER_CHK_DIS
            
            NOTIFIER_CHK_DIS -- "Evet" --> NOTIFIER_REQ_DIS("Discord Webhook'a Req At")
            NOTIFIER_CHK_DIS -- "Hayır" --> NOTIFIER_FINISH_NOT("İşlem Bitti")
            NOTIFIER_REQ_DIS --> NOTIFIER_FINISH_NOT
        end
        subgraph SG_OTA ["OTA Modülü"]
            direction TB
            %% İstek Girişi
            OTA_START(OTA_POST /ota/update Dosya Icerir) --> OTA_CHK_ZIP{Zip/Tar<br>Geçerli mi?}
            
            %% Güvenlik ve Extract
            OTA_CHK_ZIP -- Hayır --> OTA_RET_ERR(Hata:<br>Dosya Bozuk veya Geçersiz)
            OTA_CHK_ZIP -- Evet --> OTA_EXTRACT_TMP(Geçici /tmp/OTA_sentry_upd<br>Klasörüne Aç)
            
            OTA_EXTRACT_TMP --> OTA_CHK_SIG{İmza/Checksum<br>Doğru mu?}
            OTA_CHK_SIG -- Hayır --> OTA_ABORT_UPD(Güvenlik İptali:<br>Geçersiz Paket)
            
            %% Kopyalama ve Yeniden Başlatma
            OTA_CHK_SIG -- Evet --> OTA_SHT_DOWN(Güvenli Mod<br>Tüm Motorları Sustur E Stop)
            
            OTA_SHT_DOWN --> OTA_CPY_FILES(Rsync veya Shutil ile<br>Kök Dizini Üzerine Yaz)
            
            OTA_CPY_FILES --> OTA_PIP_DEP{Yeni OTA_requirements_txt<br>var mı}
            OTA_PIP_DEP -- Evet --> OTA_RUN_PIP(Subprocess<br>pip install -r req txt)
            OTA_PIP_DEP -- Hayır --> OTA_TRIG_SYSTEMD(Systemd Servisini / PCyi<br>Yeniden Başlat Reboot)
            
            OTA_RUN_PIP --> OTA_TRIG_SYSTEMD
            OTA_TRIG_SYSTEMD --> OTA_EXIT_OK(Sistem Kapanıyor...)
        end
        subgraph SG_SCHEDULER ["SCHEDULER Modülü"]
            direction TB
            %% Zamanlayıcı Döngüsü
            SCHEDULER_START(Background Thread Her saniye uyanir) --> SCHEDULER_GET_TIME(Şu Anki Saati Al)
            
            SCHEDULER_GET_TIME --> SCHEDULER_CHK_CRON{Kayıtlı Görevlerin<br>Zamanı Geldi mi?}
            
            SCHEDULER_CHK_CRON -- Hayır --> SCHEDULER_SLEEP(sleep 1) --> SCHEDULER_START
            SCHEDULER_CHK_CRON -- Evet --> SCHEDULER_FORK_TASK(İlgili Fonksiyonu<br>Ayrı Threadde Başlat)
            
            %% Örnek Görevler
            SCHEDULER_FORK_TASK --> SCHEDULER_TASK_1(Gece 03:00<br>Sohbet Loglarını Temizle)
            SCHEDULER_FORK_TASK --> SCHEDULER_TASK_2(Sabah 08:00<br>Otonomi Uyanma Titremesi)
            SCHEDULER_FORK_TASK --> SCHEDULER_TASK_3(Her 30dk<br>Battery Metrik Logla)
            
            SCHEDULER_TASK_1 --> SCHEDULER_SLEEP
            SCHEDULER_TASK_2 --> SCHEDULER_SLEEP
            SCHEDULER_TASK_3 --> SCHEDULER_SLEEP
        end
        subgraph SG_TELEMETRY ["TELEMETRY Modülü"]
            direction TB
            %% Telemetri Kayıt Alma
            TELEMETRY_EVT_IN("Herhangi bir olay (Event)<br>(Örn: arduino.telemetry)") --> TELEMETRY_TELEM_RECORD("Değişkeni Hafızaya Kaydet")
            
            TELEMETRY_TELEM_RECORD --> TELEMETRY_CHK_KEY{"Gelen Veri<br>Tipi?"}
            
            TELEMETRY_CHK_KEY -- "Sensör Verisi" --> TELEMETRY_SET_SENS("telemetry['imu_pitch'] = 45")
            TELEMETRY_CHK_KEY -- "Robot Pozu" --> TELEMETRY_SET_POSE("telemetry['current_pose'] = 'stand'")
            TELEMETRY_CHK_KEY -- "Ping" --> TELEMETRY_SET_PING("Ping Gecikmesini (ms) Yaz")
            
            %% Prometheus Formatına Çevrilme
            TELEMETRY_HTTP_GET("GET /telemetry/metrics") --> TELEMETRY_LOOP_VARS("Tüm Hafızayı Gez")
            
            TELEMETRY_LOOP_VARS --> TELEMETRY_FMT_PROM("SentryBOT_metric type imu 45 SentryBOT_metric type ram 1024")
            
            TELEMETRY_FMT_PROM --> TELEMETRY_RET_TXT("Düz Metin (Plaintext)<br>Döndür")
        end
    end
    %% Katmanlar Arasi Yerlesim Zorlamasi
    LAYER_SENSE ~~~ LAYER_CORE
    LAYER_CORE ~~~ LAYER_AI
    LAYER_AI ~~~ LAYER_ACT
    LAYER_ACT ~~~ LAYER_BG
    %% GERCEK VERI AKISLARI
    SG_GATEWAY --> SG_AUTONOMY
    SG_GATEWAY --> SG_ARDUINO_SERIAL
    SG_GATEWAY --> SG_CAMERA
    WAKEWORD_WAIT_AUDIO -- "Tetik" --> SPEECH_START
    SPEECH_EXTRACT_TEXT -- "Metin" --> AUTONOMY_S_ADD_TXT
    CAMERA_SIGNAL_EVENT --> VLM_BRIDGE_START
    VLM_BRIDGE_IDENT -- "Kişi Algılandı" --> AUTONOMY_S_MOOD_B
    AUTONOMY_A_CHK_TXT -- "Soru" --> OLLAMA_API_IN
    OLLAMA_P_SUCCESS --> AUTONOMY_DO_OP
    AUTONOMY_DO_OP -- "/speak/say" --> SPEAK_API_REQ
    AUTONOMY_DO_OP -- "/neopixel" --> NEOPIXEL_API_REQ
    AUTONOMY_DO_OP -- "/animate" --> ANIMATE_API_REQ
    ANIMATE_ACT_SRV -- "Serial Req" --> ARDUINO_SERIAL_API_CALL
    CALIBRATION_SEND_ARDU --> ARDUINO_SERIAL_API_CALL
    INTERACTIONS_HTTP_REQ --> NEOPIXEL_API_REQ
```

## 🔄 Yaşam Döngüsünde Kritik Dönüm (Karar) Noktaları (Global Decisions)

Bu diyagramlar detayları kendi dosyalarında saklasa da, sistem geneli kararları burada özetleyebiliriz:

### 1. Kim Konuşuyor? (Access Control)
VLM'den gelen isim ve Arduino'dan okunan `g_lastOwnerUid` devamlı kontrol edilir.
- **İf:** Sesli bir soru geldi (`"Ne düşünüyorsun?"`) ve Owner kilidi açık (`require_owner: true`);
  - Robot soran yüze (Vision) veya RFID sensörüne bakar.
  - Eğer sahip yakında değilse soruyu Ollama LLM'e göndermeyi reddeder. Kırmızı gözlerle uyarı çalar.
  - Sahipse LLM'e gönderir.

### 2. Yapılandırılmış LLM mi Yoksa Regex mi?
Ollama 8B / LLaMA tarzı modeller her daim `{"text": "", "actions":[]}` düzgün JSON şeması veremezler (Syntax error atarlar).
- **Trz / Catch:** Ollama, API'dan string okur, `json.loads` dener. Eğer patlarsa Modül kendini kilitlemez. Autonomy `extract_llm_tags` (Regex Parser) devreye girer; textin içerisindeki `<speak>merhaba</speak>` gibi kalıntıları regex ile arayıp, zoraki JSON actions dictionary'sine kendisi paketler ve beyne sunar. Böylece robot çökmez.

### 3. CPU'yu Koruma Mekanizmaları (Throttling)
Raspberry Pi 5 cihazında ısı ve yük problemlerini kısmak için if blokları kurulmuştur.
- **VLM:** OpenCV tabanlı yüz algılama/takip döngüsü, hedef FPS sınırları ve tracker kayıp eşiği ile gereksiz CPU yükünü bastırır.
- **Wakeword:** Mikrofon sürekli dinler ancak STT/ASR (Whisper vb) kapalıdır. **Sadece** "Hey Sentry" wakeword tespit eden küçük işlem (Porcupine) tetiklendiğinde ASR 5 saniyeliğine çalıştırılır. Enerji tasarrufu en üst seviyeye çıkarılır.

## Sonuç

SentryBOT devasa özelliklerini, Gateway'in modüler bağımsız mimarisiyle ayakta tutar. Bir modülün API (HTTP) servisi çökse dahi, Autonomy `ServiceClient` üzerindeki 1 saniyelik API Timeout'lar sağolsun diğer özellikleri çalışmaya, robot "hayatta" kalmaya devam eder. Her bir modül bağımsız çalışacak mantığa (Microservice Pattern) oturtulmuştur.

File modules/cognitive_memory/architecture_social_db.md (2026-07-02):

# Social DB Modülü Mimarisi

Social DB modülü (`modules/social_db`), robotun kişi tanıma, ilişki hafızası, sohbet geçmişi ve mood/etkileşim telemetrisini tek bir SQLite dosyasında (WAL modlu, thread-safe) birleştiren veri katmanıdır. HTTP yüzeyi yoktur; `vlm_bridge`, `autonomy`, `agent_core`, `config_center` ve `admin_ui` tarafından kütüphane olarak içe aktarılır.

## 🏗️ İş Akışı ve Karar Mekanizmaları (Flowchart)

```mermaid
flowchart TD
    INIT("SocialDB path ile baslatilir") --> CONN("sqlite3.connect<br>check_same_thread=False")
    CONN --> WAL_CHK{"wal parametresi<br>True mu?"}
    WAL_CHK -- "Evet" --> SET_WAL("PRAGMA journal_mode=WAL")
    WAL_CHK -- "Hayir" --> AUTO_CHK
    SET_WAL --> AUTO_CHK{"auto_migrate<br>True mu?"}

    AUTO_CHK -- "Evet" --> MIGRATE("migrate calisir:<br>CREATE TABLE IF NOT EXISTS + schema_version kaydi")
    AUTO_CHK -- "Hayir" --> ATTACH_REPOS
    MIGRATE --> ATTACH_REPOS("10 repository ornegi<br>olusturulup self'e baglanir")

    ATTACH_REPOS --> READY("db.persons / db.moments / ...<br>kullanima hazir")
    READY --> CLOSE("db.close ile<br>baglanti kapatilir")
```

## 🔄 İlişkisel Etkileşimler (Veri Akışı)

```mermaid
erDiagram
    SocialDB ||--o{ PersonsRepo : owns
    SocialDB ||--o{ FaceDescriptorsRepo : owns
    SocialDB ||--o{ SightingsRepo : owns
    SocialDB ||--o{ ChatEpisodesRepo : owns
    SocialDB ||--o{ RelationshipsRepo : owns
    SocialDB ||--o{ MomentsRepo : owns
    SocialDB ||--o{ MoodSnapshotsRepo : owns
    SocialDB ||--o{ RitualsRepo : owns
    SocialDB ||--o{ InteractionEventsRepo : owns
    SocialDB ||--o{ OwnerSessionsRepo : owns

    PersonsRepo ||--o{ FaceDescriptorsRepo : person_id
    PersonsRepo ||--o{ SightingsRepo : person_id
    PersonsRepo ||--o{ ChatEpisodesRepo : person_id
    PersonsRepo ||--o{ MomentsRepo : person_id

    VlmBridge ||--o{ SocialDB : get_default
    Autonomy ||--o{ SocialDB : get_default
    AgentCore ||--o{ SocialDB : get_default
    AdminUI ||--o{ SocialDB : people_snapshot
```

## ⚙️ Detaylı Karar Mantığı (if/else)

1. **Tek Paylaşımlı Bağlantı + Kilit**
   - `SocialDB`, `check_same_thread=False` ile açılan tek bir `sqlite3.connect` bağlantısını `threading.RLock` arkasında paylaşır. **`if`** birden fazla thread aynı anda yazmaya çalışırsa, `execute`/`transaction` çağrıları kilidi sırayla alır; SQLite seviyesinde `BEGIN IMMEDIATE` ile yazma çakışmaları engellenir.
2. **Canonical İsim ile Tekilleştirme**
   - `PersonsRepo.upsert`, ismi `_canon()` ile (strip + lowercase) normalize eder. **`if`** aynı `canonical_name` zaten varsa mevcut kayıt güncellenir (seen_count artırılabilir); **değilse** yeni `person_id` (`uuid4` kısaltması) ile satır eklenir — aynı kişi için birden fazla kayıt oluşmaz.
3. **Idempotent Migrasyon**
   - `_migrate()` tüm DDL'i `CREATE TABLE IF NOT EXISTS` ile çalıştırır ve `schema_version` tablosuna `INSERT OR IGNORE` yapar. **`if`** modül tekrar tekrar başlatılırsa (örn. testte veya servis restart'ında) migrasyon zararsızca tekrarlanabilir ve mevcut veriye dokunmaz.
4. **Süreç Geneli Varsayılan Örnek**
   - `get_default()` / `set_default()`, modüller arası tekil `SocialDB` paylaşımını sağlar. **`if`** hiçbir modül henüz `set_default()` çağırmadıysa, `get_default()` `None` döner ve çağıran taraflar (örn. `agent_core.tools.search_social_memory`) bunu zarifçe "Social memory unavailable." mesajına çevirir; bir alt sistemin sosyal hafızayı kullanamaması sistemin geri kalanını engellemez.

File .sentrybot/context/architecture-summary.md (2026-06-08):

# SentryBOT — Mimari Özet (Architecture Summary)

> AI asistanlar bu dosyayı okuyarak sistemin büyük resmini anlar. Detaylar için `docs/ARCHITECTURE.md` dosyasına bakın.

## Sistem Genel Bakışı

SentryBOT, Raspberry Pi 5 üzerinde çalışan, modüler mikro-servis mimarisine sahip otonom bir robot platformudur. Arduino ile seri iletişim, OpenCV ile görüntü işleme, Ollama LLM ile yapay zekâ yetenekleri entegre eder.

## 5 Katmanlı Mimari

```mermaid
flowchart TB
    subgraph L1["1. ALGI KATMANI"]
        camera["Camera<br/>MJPEG stream"]
        speech["Speech<br/>ASR + DOA"]
        vlm["VLM Bridge<br/>Yüz algılama"]
        wakeword["Wakeword<br/>Hey Sentry"]
        hw["Hardware<br/>CPU/RAM/Temp"]
    end

    subgraph L2["2. BEYİN KATMANI"]
        gateway["Gateway<br/>API Bootstrapper<br/>Port 8080"]
        autonomy["Autonomy<br/>Sense-Think-Act"]
        agent["Agent Core<br/>3-Layer Agent"]
        state["State Manager<br/>Thread-safe store"]
        config_c["Config Center<br/>Hot-reload"]
    end

    subgraph L3["3. AI / RAG KATMANI"]
        ollama["Ollama<br/>LLM Chat<br/>Port 8099"]
    end

    subgraph L4["4. EYLEM KATMANI"]
        arduino["Arduino Serial<br/>NDJSON komut"]
        animate_m["Animate<br/>YAML servo"]
        neo["NeoPixel<br/>LED animasyon"]
        speak_m["Speak (TTS)<br/>Port 8083"]
        piservo["PiServo<br/>GPIO PWM"]
        oled["OLED Faces"]
    end

    subgraph L5["5. ARKA PLAN"]
        sched["Scheduler"]
        diag["Diagnostics"]
        log_m["Logwrapper"]
        telem["Telemetry"]
        ota_m["OTA Update"]
        notif["Notifier"]
    end

    L1 --> L2
    L2 --> L3
    L3 --> L2
    L2 --> L4
    L4 --> L5
```

## Temel Veri Akışı

```
Wakeword ──trigger──→ Speech (ASR açılır)
Speech ──metin──→ Autonomy (Sense aşaması)
Camera ──frame──→ VLM Bridge (yüz algılama)
VLM Bridge ──kişi bilgisi──→ Autonomy (mood güncelle)
Autonomy ──soru──→ Ollama (LLM chat)
Ollama ──yanıt + actions──→ Autonomy (Act aşaması)
Autonomy ──HTTP──→ Speak (TTS), NeoPixel (LED), Animate (servo)
Animate/VLM ──serial──→ Arduino Serial ──NDJSON──→ Arduino
Interactions ──kural motoru──→ NeoPixel
```

## Gateway Bootstrap Mekanizması

1. `run_robot.py` → `create_app()` çağırır
2. `bootstrap(app, cfg)` → `config.yml`'deki `include` sözlüğünü okur
3. Her `include.<module>: true` için `_include_<module>(app, cfg)` çağrılır
4. Modül başarısızsa → warning loglanır, diğer modüller devam eder
5. Tüm modüller bağımsız çalışır (Microservice Pattern)

## Agent Core — 3 Katmanlı Ajan

```
Layer 1: Router/Planner → İsteği uygun sub-agent'lara yönlendirir
Layer 2: Module Sub-Agent → Domain-specific tool çalıştırır
Layer 3: Main Persona → Tutarlı final cevap üretir
```

Tüm katmanlar aynı Ollama modeli üzerinden çalışır (tek model stratejisi: `qwen3.5:9b`).

## Autonomy — Sense-Think-Act Döngüsü

```
SENSE → Konuşma var mı? Ses yönü değişti mi? Kişi görüldü mü?
THINK → Duygu bozunması, sıkılma kontrolü, uyku saati kontrolü
ACT   → LLM yanıtını parse et, donanım HTTP çağrıları yap
```

### Duygusal Model (Affective Model)

- **Mood eksenleri:** happiness, energy, curiosity, fear, **anger** (öfke ekseni
  `anger>45 → anger`, `anger>75 → furious` baskın duygularını üretir).
- **Affective appraisal** (`services/affective_appraisal.py` + `config/appraisal.yml`):
  semantik olayları (`user_rude`, `owner_returned`, `command_failed`…) mood
  deltalarına çevirir → duygular zamansal bozunmadan değil **nedenden** doğar.
- **Tek duygu sözlüğü:** tüm görsel/işitsel çıktılar `modules/common` kanonik
  duygu vocab'ından çözülür (eyes/LEDs/ears/tone aynı taksonomi).
- **Expression Director** (`services/expression_director.py`): tek çağrıda
  gözler + LED + kulaklar + kafa + ses tonunu eşgüdümlü tetikler (`brain.express`).

### Sürekli Çevre Algısı (Continuous Perception)

- **Living-vision sampling:** `vlm_bridge` inference döngüsü ve uzak ingest yolu
  `VisionSampler`'a owner/yeni-kişi/tehlike/ani-hareket/sıkılma sinyallerini
  besler → sahne bağlamı koşullu olarak arkaplanda yenilenir.
- **İçerik-temelli önem:** `compute_importance` cache'e bağlı; tehlike/owner/
  yenilik gerçek `importance_score` üretir (hardcode değil).
- **WorldState environment:** sahne özeti/nesneler/tehlikeler/kişiler agent_core
  `WorldState`'e işlenir ve LLM bağlamına enjekte edilir (`inject_world_state`).
- **Sahne yeniliği:** autonomy `_track_scene_context` token-farkıyla yeniliği
  ölçer, `environment.scene_changed` etkileşim olayı yayar (kulak/LED tepkisi).
- **Proaktif betimleme:** `ProactivePlanner` boştayken yeni/önemli sahneyi
  doğal dille anlatır (`companion.scene_comment`).

### Doğal Konuşma (Natural Speech)

- **Duygulu prosodi:** `speak` tonu artık Piper sesini de şekillendirir
  (`_tone_to_piper` → `length_scale`/`noise_w`); ton `agent_core` kuyruğundan
  TTS'e kadar korunur (`_handle_speak` tone forward).
- **Tek ton kaynağı:** autonomy `_tone_profile` kanonik duygu vocab'ından
  çözülür → ses/göz/LED/kulak aynı duygu taksonomisini paylaşır.
- **Disfluency/filler:** `SpeakService._enrich_text_for_speech` olasılıkla ve
  duygu-havuzuna göre doğal dolgu ekler ("Şey,", "Hmm,", "Aa,").
- **Doğal barge-in:** `BargeInController` robot konuşurken kullanıcının anlamlı
  konuşmasıyla (sadece wakeword değil) sözü kesmesine izin verir.

### Firmware Canlılık Köprüsü (Firmware Liveliness Bridge)

- **Kontrat komutu:** `arduino_serial/contract.py` `build_liveliness_cmd` +
  `validate_liveliness_cmd` (elle payload YOK) → `/arduino/request` ile gönderilir.
- **Firmware-native hareket:** Mega `xCommands.h` `liveliness` komutunu işler,
  `livelinessTick()` ana döngüde kafa servolarında yumuşak sinüs nefes/mikro-
  hareket üretir (Pi köprüsü kısa süre dursa bile canlı kalır).
- **Mood→hareket:** autonomy `LivelinessScheduler` baskın duygu+enerjiden
  genlik/tempo/mod üretir (excited=büyük/hızlı, tired=küçük/yavaş, anger=micro).
- **Akıllı gönderim:** brain `_liveliness_tick` yalnızca parametre değişince ya da
  `refresh_interval_s` geçince yollar; konuşma/takip/uyku sırasında bastırılır.

### Öğrenme ve Adaptasyon (Learning & Adaptation)

- **Tek çıkarım kaynağı:** `PreferenceLearner` fact + tercih regex'lerini
  `MemoryConsolidator` ve `RelationshipMemory` arasında paylaşır.
- **Konuşmacı köprüsü:** autonomy `agent.step(..., speaker=)` → `WorldState.speaker`
  → consolidator facts'i doğru kişinin `social_db` kaydına yansıtır.
- **Geri bildirim döngüsü:** `InteractionFeedbackLearner` övgü/kaba sözü
  `trust_score` + moment salience'e çevirir; enrichment `trust=high/low` ipucu verir.
- **Agent aracı:** `search_social_memory` kişi bazlı tercih/moment/trust sorgular
  (epizodik `search_memory`'ye ek).
- **Proaktif adaptasyon:** `ProactivePlanner` düşük trust'ta callback atlar,
  yüksek trust'ta daha sıcak tercih hatırlatması kullanır.

## Güvenlik ve Dayanıklılık

- **Owner kontrolü:** VLM + RFID ile sahip doğrulaması
- **LLM fallback:** JSON parse başarısızsa → regex ile XML tag ayrıştırma
- **CPU throttling:** VLM FPS sınırı, Wakeword hafif işlem
- **API timeout:** ServiceClient üzerinde 1s timeout → modül çökse bile robot hayatta
- **Safety filter:** Servo açı sınırları, stepper hız limiti, lazer süre limiti

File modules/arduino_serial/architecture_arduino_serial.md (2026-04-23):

# Arduino Serial Modülü Mimarisi

Arduino Serial modülü (`modules/arduino_serial`), komut kontratını yöneten katmandır. Üretimde Raspberry Pi komutları ESP bridge'e HTTP ile gönderir; ESP bu komutları Arduino Mega'ya NDJSON/UART olarak aktarır.

## 🏗️ İş Akışı ve Karar Mekanizmaları (Flowchart)

Aşağıdaki diyagram, seri portun nasıl başlatıldığını, arka plandaki okuma döngüsünü, ve gelen/giden JSON mesajlarının nasıl filtrelendiğini (if/else) gösterir:

```mermaid
flowchart TD
    %% Başlatma Mantığı
    START([start]) --> CHK_THREAD{"Okuma Thread'i <br> çalışıyor mu?"}
    CHK_THREAD -- Evet --> IGNORE([Hiçbir Şey Yapma])
    CHK_THREAD -- Hayır --> FIND_PORT(Seri Portu Bul <br> _autodetect_port)
    
    FIND_PORT --> CHK_PORT{"Port Bulundu mu?"}
    CHK_PORT -- Hayır --> ERR_START([HATA: Port Yok veya Erişilemez])
    CHK_PORT -- Evet --> OPEN_SERIAL(SerialTransport Başlat)
    
    OPEN_SERIAL --> CREATE_THREADS(Send ve Read <br> Queue Oluştur)
    CREATE_THREADS --> RUN_THREAD[Arka Plan _read_loop Oku]

    %% Arka Plan Okuma Döngüsü (Read Loop)
    subgraph ReadLoop [Arka Plan Okuma Akışı]
        direction TB
        LOOP_START((Döngü Başı)) --> READ_LINE{"Seri Porttan<br>Satır Oku"}
        READ_LINE -- Boş / Timeout --> LOOP_START
        READ_LINE -- Veri Var --> PARSE_JSON{"JSON Parse <br> Başarılı mı?"}
        PARSE_JSON -- Hayır --> LOG_ERR[Hata Logla] --> LOOP_START
        PARSE_JSON -- Evet --> INGEST(JSON Verisini İşle <br> _ingest_message)

        INGEST --> CHK_TYPE{Gelen Mesaj Türü}
        
        CHK_TYPE -- RFID Olayı --> EVENT_RFID[RFID Handler <br> _record_rfid / Webhook] --> LOOP_START
        CHK_TYPE -- Telemetri --> EVENT_TLM[Telemetri Handler <br> Global Durum] --> LOOP_START
        CHK_TYPE -- Yanıt (ok / error) --> QUEUE_PUSH[Uygulama Yanıt<br>Kuyruğuna Koy] --> LOOP_START
    end
    
    RUN_THREAD --> LOOP_START

    %% Komut Gönderme Akışı
    subgraph WriteCycle [Komut Gönderme - send/request]
        direction TB
        API_CALL([request_cmd]) --> MAKE_JSON(JSON'a Çevir + <br> Satır Sonu Ekle)
        MAKE_JSON --> CHK_ALIVE{"Bağlantı Açık mı?"}
        CHK_ALIVE -- Hayır --> RET_NONE([None Döndür])
        CHK_ALIVE -- Evet --> WRITE(Serial Write)
        WRITE --> WAIT_Q{"Okuma Kuyruğunda<br>Yanıt Bekle - Timeout"}
        WAIT_Q -- Timeout --> RET_ERR([Hata Formatı Döndür])
        WAIT_Q -- Yanıt Geldi --> RET_RESP([Yanıtı Döndür])
    end
```

## 🔄 İlişkisel Etkileşimler

```mermaid
erDiagram
    ArduinoSerialService ||--|| SerialTransport : uses
    ArduinoSerialService ||--o{ HttpCaller : provides

    SerialTransport {
        string port
        int baudrate
    }
    ArduinoSerialService {
        string last_rfid
        bool reader_active
    }
    HttpCaller {
        string request_source
        string json_command
    }
```

## ⚙️ Detaylı Karar Mantığı (if/else)

1. **`_autodetect_port(fallback_port)`**
   - **`if`** fallback `AUTO` ise: PySerial `list_ports` ile mevcut cihazları tara.
     - **İç `for` döngüsü**: `/dev/ttyUSB`, `/dev/ttyACM` önekli portları (RPi/Linux), veya `COM` önekli portları (Windows) bul. Bulursa ilkini kullan.
   - **`else`**: Belirtilen spesifik portu kullan.
   - Eğer port bulunamazsa veya cihaz hatalıysa sisteme uyarı ver (`logger.error`).
2. **`request(obj, timeout)` (Senkron Çağrı Mantığı)**
   - Arduino'ya istek gönderilir.
   - Öncesinde yanıt kuyruğu temizlenir (Eski okunmamış çöpleri temizlemek için `Empty` exception alana kadar döngü çalışır).
   - **`while`**: `timeout` süresince `_lines` kuyruğunu bekle.
     - **`if`** doğru formatta cevap gelirse dön, yoksa döngüde beklemeye devam et.
     - Zaman aşımı olursa (Arduino yanıt vermedi), otomatik `{"error": "timeout"}` simüle edip döndür.
3. **RFID Yetkilendirmesi (`authorize_rfid`)**
   - **`if`** `uid` parametresi verilmişse: Normalizasyon yapılır (`F3-A1...` -> `F3A1...`), kuyruklar temizlenir ve UID özel bir değişkende 5 saniye boyunca (window) tutulur, bu sürede gelen aynı UID okumaları gözden kaçmaması içindir.

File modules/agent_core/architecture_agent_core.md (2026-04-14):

# Agent Core — Mimari Dokümantasyon

## Genel Bakış

Agent Core, SentryBOT'un otonom karar verme, cevreyi algilama ve tool kullanma katmanidir.
Yeni surumde mimari **3 katmanli agent** modeline tasinmistir:

1. Router/Planner katmani
2. Modul bazli Sub-Agent katmani
3. Main Persona (final cevap) katmani

Bu uc katman da tek Ollama modeli uzerinden calisir, sadece sorumluluklari farklidir.

## Modül Yapısı

```
modules/agent_core/
├── xAgentCoreService.py      # Servis başlatıcı
├── config_loader.py          # config.yml okuyucu
├── config/
│   └── config.yml            # Modül ayarları
├── services/
│   ├── __init__.py           # Re-export proxy
│   ├── agent.py              # Ana orkestratör (Native ReAct Loop)
│   ├── safety_filter.py      # Donanım güvenlik sınırlayıcı (servolar vb.)
│   ├── memory.py             # SQLite epizodik bellek (Kalıcı bellek)
│   ├── slam.py               # Topolojik harita + BFS yol bulma
│   ├── tools.py              # LLM araç tanımları (10 adet Native Tool)
│   ├── world_state.py        # Sensör durumu (Pil, ultrasonik vb.)
│   ├── sensor_loop.py        # Arka plan sensör okuyucu (Thread)
│   ├── idle_behavior.py      # Boşta kalma nefes efekti
│   └── tri_layer.py          # Router + sub-agent profil tanimlari
├── architecture_agent_core.md# Mimari dokümantasyon
└── README.md                 # Genel bilgi
```

## Veri Akisi (Tri-Layer Agent Flow)

```mermaid
flowchart TD
    MIC[Mikrofon / Sensörler] --> AB[AutonomyBrain]
    AB -->|agent.step| AO[AgentOrchestrator]

    subgraph AgentCore["Agent Core Pipeline"]
        AO --> WS[WorldState]
        WS --> L1[Layer 1: Router / Planner]

        L1 --> L2A[Layer 2: Module Sub-Agent A]
        L1 --> L2B[Layer 2: Module Sub-Agent B]
        L1 --> L2N[Layer 2: Module Sub-Agent N]

        L2A <-->|Tool Calls| TR[ToolRegistry]
        L2B <-->|Tool Calls| TR
        L2N <-->|Tool Calls| TR

        TR --> SF[SafetyFilter]
        TR --> MEM[EpisodicMemory]
        TR --> SLAM[TopologicalMap]

        L2A --> L3[Layer 3: Main Persona Finalizer]
        L2B --> L3
        L2N --> L3
    end

    L3 --> RESP[Final User Response]
    SF --> HAL["HAL Layer: HTTP via ServiceClient"]

    subgraph HALLayer["Hardware Abstraction Layer"]
        HAL --> SS["ServoService move_head"]
        HAL --> LS["LightsService set_lights"]
        HAL --> MS["MotorService or AudioService"]
    end
    
    SS -->|/arduino/request| ARD[Serial Gateway]
```
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

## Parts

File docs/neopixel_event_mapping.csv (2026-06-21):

source_event | oled | neopixel_action | animate_servo | why | reference
wakeword.detected | animation/listening | TWINKLE;BREATHE base | head pan/tilt | Dikkat + dinleme yüzü | modules/autonomy/config/config.yml scenes.wakeword_reaction
speech.start | animation/thinking | PULSE | — | Konuşma başladı | modules/interactions/config/config.yml
speech.end | bitmap/normal | COMET | — | Konuşma bitti | modules/interactions/config/config.yml
autonomy.excited | gesture/excited | RAINBOW_CYCLE | — | Heyecan | modules/interactions/config/config.yml
autonomy.look_around | animation/scanning | COMET | look_around | Çevre tarama | modules/autonomy/config/config.yml
autonomy.blink | gesture/blink | RANDOM_BLINK | blink | Göz kırpma | modules/interactions/config/config.yml
autonomy.stretch | gesture/look_up | WAVE | stretch | Esneme | modules/interactions/config/config.yml
autonomy.bored | bitmap/bored | PULSE | — | Sıkıntı | modules/interactions/config/config.yml
autonomy.monologue | animation/thinking | TWINKLE | — | Monolog | modules/interactions/config/config.yml
vision.focus | bitmap/focused | COMET | vision_focus | Odaklanma | modules/autonomy/services/brain_parts/vision.py
vision.person | animation/searching | owner_welcome+COMET | owner_scan | Kişi algılandı | modules/autonomy/config/config.yml
owner.scan | gesture/look_left | COMET | owner_scan | Sahip tarama | modules/autonomy/config/config.yml
owner.temp_granted | bitmap/happy | THEATER_CHASE | temp_owner | Geçici sahip | modules/interactions/config/config.yml
owner.temp_revoked | bitmap/nervous | PULSE | — | Erişim iptal | modules/interactions/config/config.yml
owner.locked | bitmap/scared | METEOR | — | Kilitli mod | modules/interactions/config/config.yml
error | gesture/scan_sweep | METEOR | — | Kritik hata | modules/interactions/config/config.yml
warning | bitmap/alert | PULSE | — | Uyarı | modules/interactions/config/config.yml
arduino_disconnected | — | THEATER_CHASE magenta | — | Mega bağlantı koptu | modules/interactions/config/config.yml
net_burst | — | COMET | — | Ağ patlaması | modules/interactions/config/config.yml
emotion_joy | bitmap/happy | preset:emotion_joy | look_around | Mutluluk | modules/autonomy/config/config.yml scenes.emotion_joy
emotion_curiosity | bitmap/attentive | preset:emotion_curiosity | vision_focus | Merak | modules/autonomy/config/config.yml scenes.emotion_curiosity
emotion_fear | bitmap/scared | preset:emotion_fear | — | Korku | modules/autonomy/config/config.yml scenes.emotion_fear
emotion_tired | bitmap/tired | preset:emotion_tired | stretch | Yorgunluk | modules/autonomy/config/config.yml scenes.emotion_tired
emotion_sad | bitmap/sad | preset:emotion_sad | tilt down | Üzüntü | modules/autonomy/config/config.yml scenes.emotion_sad
LLM/actions | dynamic | dynamic anim/effect | dynamic | LLM actions alanı | modules/autonomy/services/brain.py

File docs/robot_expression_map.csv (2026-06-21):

event | source_module | oled | neopixel | animate_servo | piservo | why | reference
wakeword.detected | wakeword | animation/listening | TWINKLE+jewel+BREATHE base | head pan/tilt | — | Dikkat çekici LED + dinleme yüzü; kullanıcı uyandı | modules/autonomy/config/config.yml scenes.wakeword_reaction + modules/oled_faces/config/config.yml
speech.listen.start | speech | animation/listening | — | — | — | Aktif dinleme oturumu; OLED listening animasyonu | modules/oled_faces/config/config.yml
speech.listen.end | speech | bitmap/normal | — | — | — | Dinleme bitti; nötr yüze dön | modules/oled_faces/config/config.yml
speech.start | interactions | animation/thinking | PULSE | — | — | Konuşma başladı; düşünüyor yüzü + nabız LED | modules/interactions/config/config.yml + modules/oled_faces/config/config.yml
speech.end | interactions | bitmap/normal | COMET | — | — | Konuşma bitti; kuyruk efekti + nötr yüz | modules/interactions/config/config.yml
agent.thinking | agent_core | animation/thinking | — | — | — | LLM düşünüyor; thinking activity | modules/oled_faces/config/config.yml
agent.editing | agent_core | animation/editing | — | — | — | Kod/düzenleme modu; editing activity (Pip) | modules/oled_faces/config/config.yml
agent.processing | agent_core | animation/processing | — | — | — | Arka plan işlem; processing activity | modules/oled_faces/config/config.yml
agent.connecting | agent_core | animation/connecting | — | — | — | Bağlantı bekleniyor; connecting activity | modules/oled_faces/config/config.yml
autonomy.blink | autonomy | gesture/blink | RANDOM_BLINK | blink.yml | — | Doğal göz kırpma; LED blink + servo blink anim | modules/interactions/config/config.yml
autonomy.look_around | autonomy | animation/scanning | COMET | look_around.yml | — | Çevreyi tarama; scanning yüzü + comet LED | modules/autonomy/config/config.yml
autonomy.stretch | autonomy | gesture/look_up | WAVE | stretch.yml | — | Uyanma/esneme; yukarı bakış + wave LED | modules/interactions/config/config.yml
autonomy.bored | autonomy | bitmap/bored | PULSE | — | — | Sıkıntı; düşük enerji yüz + yavaş pulse | modules/interactions/config/config.yml
autonomy.monologue | autonomy | animation/thinking | TWINKLE | — | — | Kendi kendine konuşma; thinking + twinkle | modules/interactions/config/config.yml
autonomy.excited | autonomy | gesture/excited | RAINBOW_CYCLE | — | — | Heyecan; coşkulu jest + gökkuşağı LED | modules/interactions/config/config.yml
autonomy.angry | autonomy | bitmap/furious | BREATHE red base | — | — | Öfke; kızgın yüz + kırmızı nefes LED | modules/interactions/config/config.yml
autonomy.sleep | autonomy | animation/sleep | BREATHE dark base | — | tilt down | Uyku modu; sleepy yüz + koyu breathe | modules/interactions/config/config.yml
autonomy.wake | autonomy | bitmap/normal | COMET | stretch.yml | — | Uyanış; comet + stretch anim (wake_entry scene) | modules/autonomy/config/config.yml scenes.wake_entry
autonomy.nod | autonomy | gesture/nod | — | — | — | Onay baş hareketi | modules/oled_faces/config/config.yml
autonomy.refuse | autonomy | gesture/refuse | — | — | — | Red baş hareketi | modules/oled_faces/config/config.yml
autonomy.laugh | autonomy | gesture/laugh | — | — | — | Gülme jesti | modules/oled_faces/config/config.yml
autonomy.smoke | autonomy | gesture/smoke | — | — | — | Robot özel smoke jesti (Pip'te yok) | modules/oled_faces/config/config.yml
autonomy.shiver | autonomy | gesture/shiver | — | — | — | Ürperti jesti | modules/oled_faces/config/config.yml
autonomy.squint | autonomy | gesture/squint | — | — | — | Kısık bakış | modules/oled_faces/config/config.yml
autonomy.pop | autonomy | gesture/pop | — | — | — | Şaşırma pop jesti | modules/oled_faces/config/config.yml
autonomy.roll | autonomy | gesture/roll | — | — | — | Göz devri | modules/oled_faces/config/config.yml
autonomy.cross_eyes | autonomy | gesture/cross_eyes | — | — | — | Şaşkın çapraz bakış | modules/oled_faces/config/config.yml
vision.focus | autonomy | bitmap/focused | COMET | vision_focus.yml | — | Hedefe odaklanma; focused yüz + comet + pan | modules/autonomy/services/brain_parts/vision.py
vision.person | autonomy | animation/searching | COMET+owner_welcome preset | owner_scan.yml | — | Kişi algılandı; arama yüzü + karşılama LED/servo | modules/autonomy/config/config.yml scenes.vision_greeting_*
owner.scan | autonomy | gesture/look_left | COMET | owner_scan.yml | — | Sahip tarama; sola bak + owner_scan anim | modules/autonomy/config/config.yml scenes.owner_return
owner.rfid | autonomy/interactions | gesture/wink | RAINBOW_CYCLE | — | — | RFID tanıma; göz kırp + rainbow | modules/oled_faces/config/config.yml arduino_event_map
owner.temp_granted | autonomy | bitmap/happy | THEATER_CHASE | temp_owner.yml | — | Geçici sahip onayı; mutlu yüz + chase LED | modules/interactions/config/config.yml
owner.temp_revoked | autonomy | bitmap/nervous | PULSE | — | — | Geçici erişim iptal; gergin yüz | modules/interactions/config/config.yml
owner.locked | autonomy | bitmap/scared | METEOR | — | — | Kilitli mod; korku yüzü + meteor uyarı | modules/interactions/config/config.yml
error | interactions | gesture/scan_sweep | METEOR | — | — | Kritik hata; alarm yüzü + meteor LED | modules/interactions/config/config.yml
warning | interactions | bitmap/alert | PULSE | — | — | Uyarı; alert mood + pulse | modules/interactions/config/config.yml
arduino_disconnected | interactions | — | THEATER_CHASE magenta base | — | — | Mega bağlantısı koptu; magenta chase idle | modules/interactions/config/config.yml
net_burst | interactions | — | COMET | — | — | Ağ trafiği patlaması görsel geri bildirimi | modules/interactions/config/config.yml
cpu_hot | interactions | — | BREATHE red | — | — | CPU aşırı ısınma; kırmızı breathe | modules/interactions/config/config.yml
emotion:joy | autonomy | bitmap/happy | preset emotion_joy+RAINBOW_CYCLE | look_around.yml | ears up | Mutluluk; happy yüz + joy preset + etrafa bak | modules/autonomy/config/config.yml scenes.emotion_joy
emotion:curiosity | autonomy | bitmap/attentive | preset emotion_curiosity+TWINKLE | vision_focus.yml | ears forward | Merak; attentive yüz + twinkle + odak anim | modules/autonomy/config/config.yml scenes.emotion_curiosity
emotion:fear | autonomy | bitmap/scared | preset emotion_fear+PULSE red | — | ears back | Korku; scared yüz + kırmızı pulse | modules/autonomy/config/config.yml scenes.emotion_fear
emotion:tired | autonomy | bitmap/tired | preset emotion_tired+BREATHE dim | stretch.yml | ears down | Yorgunluk; tired yüz + dim breathe + esneme | modules/autonomy/config/config.yml scenes.emotion_tired
emotion:sadness | autonomy | bitmap/sad | preset emotion_sad+PULSE blue | — | tilt down | Üzüntü; sad yüz + mavi pulse | modules/autonomy/config/config.yml scenes.emotion_sad
emotion:anger | autonomy | bitmap/angry | preset emotion_angry | — | — | Öfke; angry mood (autonomy express) | modules/oled_faces/config/config.yml
emotion:smoking | autonomy | bitmap/smoking | — | — | — | Robot özel chill/smoke mood (SentryBOT only) | modules/oled_faces/services/eyes/moods.py
scene.emotion_joy | autonomy | bitmap/happy | preset emotion_joy | look_around.yml | — | Sahne tetikleyicisi: joy paketi | modules/oled_faces/config/config.yml
scene.emotion_curiosity | autonomy | bitmap/attentive | preset emotion_curiosity | vision_focus.yml | — | Sahne tetikleyicisi: curiosity paketi | modules/oled_faces/config/config.yml
state:listening | state_manager | animation/listening | — | — | — | Global state listening → OLED listening | modules/oled_faces/config/config.yml state_map
state:thinking | state_manager | animation/thinking | — | — | — | Global state thinking | modules/oled_faces/config/config.yml state_map
state:speaking | state_manager | animation/thinking | — | — | — | Konuşma sırasında thinking yüzü (TTS aktif) | modules/oled_faces/config/config.yml state_map
state:sleeping | state_manager | animation/sleep | BREATHE dark | — | — | Uyku state; sleep animasyon | modules/oled_faces/config/config.yml state_map
state:low_battery | state_manager | bitmap/battery_low | PULSE orange | — | — | Düşük batarya uyarısı | modules/oled_faces/config/config.yml state_map
agent.debugging | agent_core | animation/debugging | — | — | — | Hata ayıklama yüzü (Pip) | modules/oled_faces/config/config.yml
agent.building | agent_core | animation/building | — | — | — | Derleme/inşa animasyonu | modules/oled_faces/config/config.yml
agent.testing | agent_core | animation/testing | — | — | — | Test tüpü animasyonu | modules/oled_faces/config/config.yml
agent.deploying | agent_core | animation/deploying | — | — | — | Deploy balina animasyonu | modules/oled_faces/config/config.yml
agent.glitch | agent_core | animation/glitch | — | — | — | Glitch corruption (kendi kendine biter) | modules/oled_faces/config/config.yml
agent.ping_pong | agent_core | animation/ping_pong | — | — | — | BLE/sonar ping-pong | modules/oled_faces/config/config.yml
agent.waiting | agent_core | animation/waiting | — | — | — | Terminal bekleme cursor | modules/oled_faces/config/config.yml
agent.chill | agent_core | bitmap/chill | — | — | — | Rahat mood (Pip) | modules/oled_faces/config/config.yml
activity:debugging | manual | animation/debugging | — | — | — | Katalog event tetikleyici | GET /oled_faces/catalog
activity:deploying | manual | animation/deploying | — | — | — | Katalog event tetikleyici | POST /oled_faces/event
emotion:chill | manual | bitmap/chill | — | — | — | Katalog mood tetikleyici | POST /oled_faces/manual

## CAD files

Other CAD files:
3d_Print/Body/Body_Completed.3mf
3d_Print/Body/Body_Top_Panels.3mf
3d_Print/Completed_Sentry/SentryBOT.3mf
3d_Print/Foot/Foot_Top_Body.3mf
3d_Print/Foot/GearBox/Gearbox_Gears.3mf
3d_Print/Head/Head_Ear/Ear_Servo_Body.3mf
3d_Print/Head/Head_Neck.3mf
3d_Print/Body/Body_Center.3mf
3d_Print/Foot/Foot_Leg_Body_Merger.3mf
3d_Print/Foot/GearBox/Gearbox_Top.3mf
3d_Print/Head/Head_Ear/Ear_Servo_Horn.3mf
3d_Print/Head/Head_Pan.3mf
3d_Print/Body/Body_Neck.3mf
3d_Print/Foot/Foot_Bottom_Body.3mf
3d_Print/Foot/GearBox/Gearbox_Gear_Bottom.3mf
3d_Print/Head/Head_Ear/Ear.3mf
3d_Print/Head/Head_Top.3mf
3d_Print/Body/Body_Spacer.3mf
3d_Print/Body/Body.f3z
3d_Print/Body/Body_Back.3mf
3d_Print/Body/Body_Bottom.3mf
3d_Print/Body/Body_Bottom_Panels.3mf
3d_Print/Body/Body_Front.3mf
3d_Print/Body/Body_Hip.3mf
3d_Print/Body/Body_Nuts.3mf
3d_Print/Body/Body_Shoulder.3mf
3d_Print/Completed_Sentry/SentryBOT.f3z
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

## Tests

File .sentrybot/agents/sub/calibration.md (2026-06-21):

# Sub-Agent: calibration-specialist

## Uzmanlık
`None` ve `calibration` modül ekosistemi.

## Bilgi kaynağı
`.sentrybot/obsidian/modules/calibration.md`

## Bileşen haritası
- —

## Dış bağlantılar (neden)
- [[arduino_serial]] (registry): Servo kalibrasyon komutlarını Arduino'ya gönderir.
- [[camera]] (http): `calibration` HTTP ile `camera` modülüne erişir: Kamera stream veya snapshot ister.

## Gelen bağlantılar (neden)
- [[gateway]] (import): `gateway` kod içinde `calibration` modülünü import eder (`api`) — Servo kalibrasyon modu.
- [[gateway]] (import): `gateway` kod içinde `calibration` modülünü import eder (`config_loader`) — Servo kalibrasyon modu.

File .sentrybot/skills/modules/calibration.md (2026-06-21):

# Skill: calibration

## Ana bileşen
- Sınıf: `None` in `modules/calibration/xCalibrationService.py`
- Mission: Servo kalibrasyon modu

## API özeti
- `GET /healthz` → `healthz()` → —
- `GET /camera/checkerboard` → `checker()` → —
- `GET /servo/sweep` → `servo_sweep()` → —

## Dış ilişkiler (neden)
- → [[arduino_serial]] (registry): Servo kalibrasyon komutlarını Arduino'ya gönderir.
- → [[camera]] (http): `calibration` HTTP ile `camera` modülüne erişir: Kamera stream veya snapshot ister.

## Gelen ilişkiler (neden)
- ← [[gateway]] (import): `gateway` kod içinde `calibration` modülünü import eder (`api`) — Servo kalibrasyon modu.
- ← [[gateway]] (import): `gateway` kod içinde `calibration` modülünü import eder (`config_loader`) — Servo kalibrasyon modu.

## Tam bilgi
`.sentrybot/obsidian/modules/calibration.md` (12 dosya, 152 satır)

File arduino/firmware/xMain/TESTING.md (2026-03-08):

SentryBOT Arduino firmware — Test talimatları (Stepper PID & Hall)

Amaç
- Kapalı döngü (Hall) stepper PID kontrolünü güvenli şekilde doğrulamak, PID kazançlarını test etmek ve EEPROM'a kaydetme/geri yükleme işlevlerini doğrulamak.

Güvenlik Önlemleri (MUST)
1. Motor sürücülerin tahrik gücünü sınırlayın veya güç kaynağını düşük voltajda başlatın.
2. Fiziksel olarak tekerlekleri/şasi bağlantılarını sabitleyin; küçük hızlarda test edin.
3. `PIN_STEPPER_ENABLE` manuel olarak düşük seviyeye alınabilmesi için erişim sağlayın.
4. Eğer motor ısınır veya anormal davranış görülürse hemen güç kesip `pid_clear_stall` komutunu gönderin.

Seri Komutlar (NDJSON)
- Temel format: Tek satır JSON, örn: {"cmd":"pid_enable","id":0,"enable":true}
- Önemli komutlar:
  - `{"cmd":"pid_enable","id":<0|1>,"enable":true|false}`
  - `{"cmd":"pid_set","id":<0|1>,"kp":<float>,"ki":<float>,"kd":<float>,"target":<steps/s>}`
  - `{"cmd":"pid_status","id":<0|1>}` -> döner: {"ok":true,"id":0,"measured":<steps/s>,"target":<steps/s>,"stalled":true|false}
  - `{"cmd":"pid_save","id":<0|1>}`
  - `{"cmd":"pid_load","id":<0|1>}`
  - `{"cmd":"pid_clear_stall","id":<0|1>}`
  - `{"cmd":"stepper_cfg","maxSpeed":<float>,"accel":<float>}`
  - `{"cmd":"home"}` ve `{"cmd":"zero_now"}` için pozisyon testleri

Manuel hızlı test akışı
1. Seri bağlantıyı açın (ör: `Serial3` bağlıysa uygun USB-UART ile) ve baud: 115200.
2. PID'i etkinleştirin (düşük hedef hızla):
  {"cmd":"pid_enable","id":0,"enable":true}
  {"cmd":"pid_set","id":0,"kp":1.0,"ki":0.0,"kd":0.05,"target":20}
3. Durumu sorgulayın: {"cmd":"pid_status","id":0}
4. Hız artışı yaparken tekerleğin fiziksel davranışını gözleyin. Eğer `stalled:true` dönerse hemen `pid_clear_stall` gönderin ve fiziksel inceleme yapın.
5. Kazançlardan memnun kalırsanız EEPROM'a kaydedin: {"cmd":"pid_save","id":0}

Otomatik test (örnek Python script)
- Repository içinde `scripts/serial_stepper_test.py` örneği bulunmaktadır. Script:
  - Seri porttan komut gönderir,
  - Hedef hızları tarar (sweep),
  - Her adımda `pid_status` dönen ölçümü loglar (CSV).

Örnek komut (Windows PowerShell):
```powershell
python .\scripts\serial_stepper_test.py --port COM4 --baud 115200 --id 0 --start 10 --stop 200 --step 10 --log pid_log.csv
```

Log formatı (CSV)
- timestamp_ms,id,target,measured,stalled,raw
- Örnek satır: 1677661234567,0,50.0,48.3,false,{"cmd":"pid_status",...}

Notlar
- İlk testleri düşük hızlarda (<=100 steps/s) yapın.
- PID kazançları `xConfig.h` içindeki varsayılanlara ayarlı. Kalıcı kaydetme `pid_save` ile yapılır.

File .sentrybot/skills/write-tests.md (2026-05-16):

# Skill: Write Tests — Test Yazma

> SentryBOT modülleri için test yazma kuralları ve kalıpları.

## Test Türleri

### 1. Smoke Test (Zorunlu)
Her modülde `tests/test_smoke.py` olmalı:
```python
"""{{MODULE_NAME}} smoke testleri — temel sağlık kontrolü."""

def test_import():
    """Modül import edilebilir mi?"""
    from modules.{{MODULE_NAME}} import {{SERVICE_NAME}}Service
    assert {{SERVICE_NAME}}Service is not None

def test_config_loader():
    """Config yüklenebilir mi?"""
    from modules.{{MODULE_NAME}}.config_loader import load_config
    cfg = load_config()
    assert isinstance(cfg, dict)

def test_service_init():
    """Service boş config ile oluşturulabilir mi?"""
    from modules.{{MODULE_NAME}} import {{SERVICE_NAME}}Service
    svc = {{SERVICE_NAME}}Service(cfg={})
    assert svc is not None

def test_router_creation():
    """API router oluşturulabilir mi?"""
    from modules.{{MODULE_NAME}}.api.router import get_router
    router = get_router()
    assert router is not None
```

### 2. Unit Test
Tek bir fonksiyonu/sınıfı izole test etme:
```python
"""{{MODULE_NAME}} unit testleri."""
import pytest
from unittest.mock import MagicMock, patch

def test_specific_function():
    from modules.{{MODULE_NAME}}.services.some_service import SomeClass
    obj = SomeClass(cfg={"key": "value"})
    result = obj.do_something(input_data)
    assert result == expected_output

def test_error_handling():
    from modules.{{MODULE_NAME}}.services.some_service import SomeClass
    obj = SomeClass(cfg={})
    with pytest.raises(ValueError):
        obj.do_something(invalid_input)
```

### 3. API Test (FastAPI TestClient)
```python
"""{{MODULE_NAME}} API testleri."""
from fastapi.testclient import TestClient
from fastapi import FastAPI

def test_status_endpoint():
    from modules.{{MODULE_NAME}}.api.router import get_router
    app = FastAPI()
    app.include_router(get_router(), prefix="/{{MODULE_NAME}}")
    client = TestClient(app)
    resp = client.get("/{{MODULE_NAME}}/status")
    assert resp.status_code == 200
    assert resp.json()["ok"] is True
```

### 4. Mock Kalıpları
```python
# Donanım bağımlılığını mock'la
@patch("modules.{{MODULE_NAME}}.services.hw.RPi.GPIO", create=True)
def test_hardware_function(mock_gpio):
    mock_gpio.input.return_value = 1
    # ...test...

# HTTP çağrısını mock'la
@patch("httpx.AsyncClient.post")
async def test_service_client(mock_post):
    mock_post.return_value = MagicMock(status_code=200, json=lambda: {"ok": True})
    # ...test...

# Arduino serial'ı mock'la
@patch("modules.arduino_serial.xArduinoSerialService.ArduinoSerialService")
def test_arduino_command(mock_serial):
    mock_serial.request_cmd.return_value = {"ok": True}
    # ...test...
```

## CI Kuralları
- Python 3.10 hedef
- `webrtcvad`, `sounddevice`, `soundfile` CI'da uninstall edilir
- Donanım gerektiren testler `@pytest.mark.skipif` ile korunur
- Timeout: collection 420s, test suite 1800s
- `--maxfail=1` ile ilk hatada durur

## Çalıştırma
```bash
# Tek modül
python -m pytest modules/{{MODULE_NAME}}/tests/ -v

# Tüm modüller
python -m pytest modules/ -q --maxfail=1

# Sadece collection kontrolü
python -m pytest --collect-only modules/{{MODULE_NAME}}/tests/ -vv
```

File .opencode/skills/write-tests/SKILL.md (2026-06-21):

---
name: write-tests
description: "SentryBOT write tests skill."
---

# write-tests

> Tüm içerik `.sentrybot/skills/write-tests.md` dosyasına taşınmıştır.

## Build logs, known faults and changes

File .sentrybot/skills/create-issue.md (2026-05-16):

# Skill: Create Issue — Issue Oluşturma

> GitHub Issue standartlarına uygun bug report ve feature request oluşturma.

## Bug Report

`.github/ISSUE_TEMPLATE/bug_report.yml` formatına uygun:

```markdown
**Açıklama:** <Hatanın kısa açıklaması>

**Beklenen davranış:** <Ne olması gerekiyordu>

**Gerçekleşen davranış:** <Ne oldu>

**Tekrar adımları:**
1. <Adım 1>
2. <Adım 2>
3. <Adım 3>

**Ortam:**
- Platform: Raspberry Pi 5
- Python: 3.10
- OS: <Raspbian/Ubuntu>
- Etkilenen modül: <modül adı>

**Log çıktısı:**
\```
<ilgili log satırları>
\```

**Ekran görüntüsü:** (varsa)
```

## Feature Request

`.github/ISSUE_TEMPLATE/feature_request.yml` formatına uygun:

```markdown
**Motivasyon:** <Neden bu özellik gerekli>

**Kullanım senaryosu:** <Nasıl kullanılacak>

**Önerilen çözüm:** <Teknik yaklaşım>

**Alternatifler:** <Düşünülen diğer yollar>

**Etkilenecek modüller:** <modül listesi>

**Ek bilgi:** (varsa)
```

## Label Önerisi

| Durum | Label |
|---|---|
| Bug | `bug` |
| Feature | `enhancement` |
| Acil | `priority:high` |
| Dokümantasyon | `documentation` |
| Arduino ile ilgili | `hardware:arduino` |

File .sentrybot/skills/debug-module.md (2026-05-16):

# Skill: Debug Module — Modül Debugging

> SentryBOT modüllerinde hata ayıklama prosedürü.

## Hızlı Teşhis

### 1. Modül Sağlık Kontrolü
```bash
# Modül import edilebilir mi?
python -c "from modules.{{MODULE_NAME}} import *; print('OK')"

# Config yüklenebilir mi?
python -c "from modules.{{MODULE_NAME}}.config_loader import load_config; print(load_config())"

# Testler geçiyor mu?
python -m pytest modules/{{MODULE_NAME}}/tests/ -v --maxfail=1
```

### 2. Log Analizi
```bash
# Son logları incele
grep -i "error\|warning\|exception" logs/ --include="*.log" | grep {{MODULE_NAME}}
```

### 3. API Sağlık Kontrolü
```bash
# Gateway üzerinden durum kontrolü
curl http://localhost:8080/{{MODULE_NAME}}/status
curl http://localhost:8080/{{MODULE_NAME}}/healthz

# Genel sistem durumu
curl http://localhost:8080/status
```

### 4. Diagnostics Modülü
```bash
# Otomatik sistem testi
curl -X POST http://localhost:8080/diagnostics/self_test
```

## Yaygın Sorunlar

| Sorun | Olası Neden | Çözüm |
|---|---|---|
| Import hatası | Eksik bağımlılık | `pip install -r modules/{{MODULE_NAME}}/requirements.txt` |
| Config hatası | YAML syntax | Config dosyasını YAML linter ile kontrol et |
| API 404 | Gateway'e kayıtlı değil | `gateway-bootstrap` skill'ini uygula |
| Arduino timeout | Seri bağlantı kopuk | `diagnostics/self_test` çalıştır |
| Modül çökmesi | Exception yakalanmamış | try/except ekle, log incele |

## İzole Test
```python
# Modülü izole çalıştırma
import sys, os
sys.path.insert(0, os.path.dirname(os.path.dirname(os.path.abspath(__file__))))
from modules.{{MODULE_NAME}}.x{{SERVICE_NAME}}Service import {{SERVICE_NAME}}Service
svc = {{SERVICE_NAME}}Service(cfg={})
svc.start()
```

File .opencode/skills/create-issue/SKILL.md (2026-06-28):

---
name: create-issue
description: "SentryBOT standartlarina uygun GitHub Issue olusturur."
---

# Create Issue

Bug report veya feature request olusturma proseduru.

## Tam Prosedur
`.sentrybot/skills/create-issue.md` dosyasini oku.

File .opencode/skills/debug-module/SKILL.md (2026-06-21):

---
name: debug-module
description: "SentryBOT debug module skill."
---

# debug-module

> Tüm içerik `.sentrybot/skills/debug-module.md` dosyasına taşınmıştır.

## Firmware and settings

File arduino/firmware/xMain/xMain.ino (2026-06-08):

#include <Arduino.h>
#include "xConfig.h"
#include "xProtocol.h"
#include "xRobot.h"
#include <EEPROM.h>
#include "xPeripherals.h"
#include "peripherals/xEbyteRadio.h"
#include "actuators/xNemaController.h"

#include "app/xLcdHub.h"
#include "app/xIrMenuController.h"
#include "app/xCommands.h"
#include "app/xCuteBuzzer.h"

Robot robot;
unsigned long lastHeartbeatMs = 0;
bool g_linkAlive = false;
bool g_linkEverAlive = false;
bool telemetryOn = false;
unsigned long telemetryInterval = 100;
unsigned long lastTelemetryMs = 0;
// Song queue

// Song queue (simple ring) with compact IDs to avoid String heap churn.
enum SongId : uint8_t {
  SONG_NONE = 0,
  SONG_WALLE,
  SONG_BB8_1,
  SONG_BB8_2,
  SONG_BB8_3,
};

const int SONG_QUEUE_CAP = 8;
uint8_t g_songQueue[SONG_QUEUE_CAP];
int g_songQueueStart = 0;
int g_songQueueCount = 0;

static inline const char* songNameFromId(uint8_t id){
  switch (id){
    case SONG_WALLE: return "walle";
    case SONG_BB8_1: return "bb8_1";
    case SONG_BB8_2: return "bb8_2";
    case SONG_BB8_3: return "bb8_3";
    default: return nullptr;
  }
}

static inline void enqueueSong(uint8_t songId){
  if (songId == SONG_NONE) return;
  if (g_songQueueCount >= SONG_QUEUE_CAP) return;
  int idx = (g_songQueueStart + g_songQueueCount) % SONG_QUEUE_CAP;
  g_songQueue[idx] = songId;
  g_songQueueCount++;
}

static inline void processSongQueue(){
  if (g_songQueueCount == 0) return;
  // g_song is global BuzzerSongPlayer; check isPlaying()
  if (!g_song.isPlaying()){
    uint8_t songId = g_songQueue[g_songQueueStart];
    g_songQueueStart = (g_songQueueStart + 1) % SONG_QUEUE_CAP;
    g_songQueueCount--;
    const char* songName = songNameFromId(songId);
    if (songName != nullptr) g_song.play(songName, g_buzzerDefaultOut);
  }
}

// Proximity beep state for HC-SR04 parking-like feedback
unsigned long g_lastProxBeepMs = 0;
bool g_proxContinuousOn = false;

#if RFID_ENABLED
RfidReader g_rfid;
String g_lastRfid;
#endif
String g_lastSpeech;
#if LCD_ENABLED
LcdDisplay g_lcd1;
  bool g_lcd1Ok = false;
LcdStatus g_lcdStatus;
#endif
#if ULTRA_ENABLED
Ultrasonic g_ultra;
float g_ultraCm = NAN;
bool g_avoidEnable = AVOID_ENABLE_DEFAULT;
#endif
#if LASER_ENABLED
LaserPair g_lasers;
#endif
#if DS18_ENABLED
Ds18b20Manager g_ds18;
#endif
#if BUZZER_ENABLED
BuzzerPair g_buzzer;
BuzzerSongPlayer g_song;
BuzzerOut g_buzzerDefaultOut = BUZZER_OUT_LOUD;
#if 1
// Runtime flag to enable both buzzers simultaneously (default: false)
bool g_buzzerBothEnabled = false;
#endif
#if BUZZER_ENABLED
// Runtime adjustable frequencies for loud and quiet buzzers (persisted to EEPROM)
uint16_t g_buzzerFreqLoud = 1500;
uint16_t g_buzzerFreqQuiet = 1200;
#endif
#endif
#if IR_ENABLED
// IrKeyReader g_ir; // Disabled: Migrating to Virtual ESP Web Remote
#endif

#if IR_ENABLED
IrMenuController g_irMenu;
void pushAlert(const String &msg) { g_irMenu.addAlert(msg); }
#else
void pushAlert(const String &msg) { /* silence */ }
#endif

#if HALL_ENCODER_ENABLED
HallEncoder g_hall0;
HallEncoder g_hall1;
#endif

static String g_rxLine;
static String g_irKey;
static String g_lcdLineTmp;

static inline void printJsonEscaped(const String &s){
  for (size_t i = 0; i < s.length(); ++i){
    char c = s[i];
    switch (c){
      case '"': SERIAL_IO.print(F("\\\"")); break;
      case '\\': SERIAL_IO.print(F("\\\\")); break;
      case '\n': SERIAL_IO.print(F("\\n")); break;
      case '\r': SERIAL_IO.print(F("\\r")); break;
      case '\t': SERIAL_IO.print(F("\\t")); break;
      default: SERIAL_IO.print(c); break;
    }
  }
}

static inline bool isOwnerUid(const char *uid){
  // "F3A186A5" (8 chars)
  return uid[0]=='F' && uid[1]=='3' && uid[2]=='A' && uid[3]=='1' && uid[4]=='8' && uid[5]=='6' && uid[6]=='A' && uid[7]=='5' && uid[8]=='\0';
}

static inline void printTelemetryJson(){
  SERIAL_IO.print(F("{\"ok\":true,\"telemetry\":true,\"pitch\":"));
  SERIAL_IO.print(robot.imu.getPitch(), 2);
  SERIAL_IO.print(F(",\"roll\":"));
  SERIAL_IO.print(robot.imu.getRoll(), 2);
  SERIAL_IO.print(F(",\"pose\":["));
  for (int i = 0; i < SERVO_COUNT_TOTAL; ++i){
    if (i) SERIAL_IO.print(',');
    SERIAL_IO.print((int)robot.servos.get(i));
  }
  SERIAL_IO.print(F("],\"stepper_pos\":["));
  SERIAL_IO.print(robot.steppers.pos1());
  SERIAL_IO.print(',');
  SERIAL_IO.print(robot.steppers.pos2());
  SERIAL_IO.print(']');
#if RFID_ENABLED
  SERIAL_IO.print(F(",\"rfid\":\""));
  printJsonEscaped(g_lastRfid);
  SERIAL_IO.print('"');
#endif
#if ULTRA_ENABLED
  SERIAL_IO.print(F(",\"ultra_cm\":"));
  if (isnan(g_ultraCm)) SERIAL_IO.print(F("null"));
  else SERIAL_IO.print(g_ultraCm, 1);
#endif
  SERIAL_IO.println('}');
}

void setup(){
  SERIAL_IO.begin(ROBOT_SERIAL_BAUD);
  SERIAL_IO.println(F("{\"info\":\"boot_start\"}"));
  g_rxLine.reserve(128);
  g_irKey.reserve(12);
  g_lcdLineTmp.reserve(22);
#if RFID_ENABLED
  g_lastRfid.reserve(16);
#endif
  g_lastSpeech.reserve(32);
  robot.begin();
  // Initialize and attach hall encoders (if enabled) after steppers are started
#if HALL_ENCODER_ENABLED
  // Load per-wheel pulses-per-rev from EEPROM if present, otherwise use config defaults
  uint16_t ppr0 = HALL_PULSES_PER_REV_0;
  uint16_t ppr1 = HALL_PULSES_PER_REV_1;
  if (EEPROM.read(EEPROM_ADDR_HALL_MAGIC) == EEPROM_HALL_MAGIC){
    uint16_t e0=0, e1=0;
    EEPROM.get(EEPROM_ADDR_HALL_PPR_0, e0);
    EEPROM.get(EEPROM_ADDR_HALL_PPR_1, e1);
    if (e0 > 0 && e0 < 100) ppr0 = e0;
    if (e1 > 0 && e1 < 100) ppr1 = e1;
  }
  // Begin hall encoders in analog mode if configured
  g_hall0.begin(HALL_PIN_0, ppr0, (bool)HALL_ANALOG_MODE, HALL_ANALOG_THRESHOLD);
  g_hall1.begin(HALL_PIN_1, ppr1, (bool)HALL_ANALOG_MODE, HALL_ANALOG_THRESHOLD);
  robot.steppers.attachHallEncoders(&g_hall0, &g_hall1);

  // Auto-load PID gains from EEPROM for each motor (if present)
  bool l0 = robot.steppers.loadPidFromEeprom(0);
  bool l1 = robot.steppers.loadPidFromEeprom(1);
  if (l0 || l1) Protocol::sendOk("pid_loaded");
#endif
  // Initialize EBYTE radio (nRF24L01 compatible) and NEMA controller
  #if EBYTE_ENABLED && defined(RADIO_CE_PIN) && defined(RADIO_CSN_PIN)
  g_ebyteRadio.begin(RADIO_CE_PIN, RADIO_CSN_PIN, 100);
#endif
  // Initialize NEMA controller
  g_nema.begin();
  // Auto-load IMU offsets if present
  if (EEPROM.read(EEPROM_ADDR_MAGIC)==EEPROM_MAGIC){ float p,r; EEPROM.get(EEPROM_ADDR_IMU_OFF,p); EEPROM.get(EEPROM_ADDR_IMU_OFF+sizeof(float),r); robot.imu.setOffsets(p,r); }
  // Load persisted buzzer frequencies if present
  #if BUZZER_ENABLED
  if (EEPROM.read(EEPROM_ADDR_BUZZER_FREQ_MAGIC) == EEPROM_BUZZER_MAGIC){
    uint16_t vfL = 0; uint16_t vfQ = 0;
    EEPROM.get(EEPROM_ADDR_BUZZER_FREQ_LOUD, vfL);
    EEPROM.get(EEPROM_ADDR_BUZZER_FREQ_QUIET, vfQ);
    if (vfL >= 200 && vfL <= 4000) g_buzzerFreqLoud = vfL;
    if (vfQ >= 200 && vfQ <= 4000) g_buzzerFreqQuiet = vfQ;
  }
  #endif
  Protocol::sendOk(F("ready"));
#if LCD_ENABLED
  Wire.begin();
#if defined(ARDUINO_ARCH_AVR)
  // Keep I2C from hanging forever AND auto-recover the bus on timeout. With
  // `reset_with_timeout=false` a single stuck slave (e.g. flaky IMU/MPU-6050)
  // could leave Wire in a state where the LCD writes that follow silently
  // fail, manifesting as blank menu rows. With `true` Wire resets itself and
  // subsequent LCD transactions succeed.
  Wire.setWireTimeout(25000, true);
#endif
  uint8_t lcd1Addr = LCD_I2C_ADDR;

  // Auto-detect LCD1 address: try configured value first, otherwise scan common I2C addresses.
  bool p1 = false;
  if (i2cDevicePresent(lcd1Addr)){
    p1 = true;
  } else {
    // Common addresses for I2C LCD backpacks and modules
    const uint8_t scanCandidates[] = {0x27, 0x3F, 0x3E, 0x26, 0x20, 0x21, 0x22, 0x23, 0x24, 0x25};
    for (size_t si = 0; si < sizeof(scanCandidates); ++si){
      uint8_t a = scanCandidates[si];
      if (i2cDevicePresent(a)){
        lcd1Addr = a;
        p1 = true;
        break;
      }
    }
  }
  g_lcd1Ok = p1;
  // Auto-promote: if only one LCD exists, prefer treating it as 16x2 (prevents 2x8 split look on 16x2 modules).
  bool onlyOne = p1;

  if (p1){
    uint8_t cols = LCD_COLS;
    uint8_t rows = LCD_ROWS;
    bool split = (bool)LCD_16X1_SPLIT_ROW;
    if (LCD_AUTO_PROMOTE_16X2_IF_SINGLE && onlyOne && cols == 16 && rows == 1){
      rows = 2;
      split = false;
    }
    g_lcd1.begin(lcd1Addr, cols, rows, split);
  }


  // LCD yoksa firmware çalışmaya devam eder; sadece LCD yazımı atlanır.
  g_lcdStatus.begin("", 0);
  g_irMenu.reset();
  g_irMenu.showHome();

    if (BOOT_STATUS_ENABLED && lcdHubAny()){
    bootUiStep(F("SentryBOT"), (const __FlashStringHelper*)F("BOOT"), BOOT_SPLASH_MS);

    // LCDs
    bootInfo("lcd1", g_lcd1Ok);
    bootUiStep(F("LCD1"), g_lcd1Ok ? (const __FlashStringHelper*)F("OK") : (const __FlashStringHelper*)F("MISSING"), g_lcd1Ok ? BOOT_STATUS_OK_MS : BOOT_STATUS_FAIL_MS);


    // I2C modules
    // Check both common MPU6050 addresses (0x68 and 0x69) because AD0 pin
    // on some modules may be pulled high (0x69).
    bool imuOk = i2cDevicePresent(IMU_I2C_ADDR) || i2cDevicePresent(0x69);
    bootInfo("imu", imuOk);
    bootUiStep(F("IMU"), imuOk ? (const __FlashStringHelper*)F("OK") : (const __FlashStringHelper*)F("MISSING"), imuOk ? BOOT_STATUS_OK_MS : BOOT_STATUS_FAIL_MS);

  #if SERVO_USE_PCA9685
    bool pcaOk = i2cDevicePresent(PCA9685_ADDR);
    bootInfo("pca9685", pcaOk);
    bootUiStep(F("SERVO"), pcaOk ? (const __FlashStringHelper*)F("PCA9685 OK") : (const __FlashStringHelper*)F("PCA9685 MISSING"), pcaOk ? BOOT_STATUS_OK_MS : BOOT_STATUS_FAIL_MS);
  #else
    bootInfo("servo_driver", true);
    bootUiStep(F("SERVO"), (const __FlashStringHelper*)F("DIRECT PINS"), BOOT_STATUS_OK_MS);
  #endif

    // Compile-time features (to give a bit of "liveliness")
    String feat = String("") + (IR_ENABLED?"IR ":"") + (RFID_ENABLED?"RFID ":"") + (ULTRA_ENABLED?"ULTRA ":"") + (LASER_ENABLED?"LASER ":"");
    if (feat.length() > 0) bootUiStep(F("FEATURES"), feat, BOOT_STATUS_STEP_MS);


    }
#endif
#if RFID_ENABLED
  g_rfid.begin(RFID_SS_PIN, RFID_RST_PIN);
#endif
#if ULTRA_ENABLED
  g_ultra.begin(ULTRA_TRIG_PIN, ULTRA_ECHO_PIN);
#endif
#if LASER_ENABLED
  g_lasers.begin(LASER1_PIN, LASER2_PIN);
#endif
#if BUZZER_ENABLED
  g_buzzer.begin(BUZZER_LOUD_PIN, BUZZER_QUIET_PIN);
  g_song.begin(&g_buzzer);
  g_song.setDefaultOut(g_buzzerDefaultOut);
  cuteBuzzerInit();
#if BOOT_BEEP
  // Boot beep uses LOUD at test freq
  g_buzzer.beepOn(BUZZER_OUT_LOUD, g_buzzerFreqLoud, 50);
#endif
#endif
#if DS18_ENABLED
  // Start DS18B20 OneWire sensors (all devices on single pin)
  g_ds18.begin(DS18_PIN);
#endif
#if IR_ENABLED
  // g_ir.begin(IR_PIN); // Disabled: Physical IR removed
  #if LCD_ENABLED
  // IR menü olayları ana LCD'de gösterilsin
  g_irMenu.setLcdPrint([](const String &top, const String &bottom){ g_lcdStatus.showTo(LCD_TGT_1, top, bottom, true); });
#endif
  g_irMenu.reset();
#endif
#if BOOT_CALIBRATION_PROMPT
  unsigned long t0 = millis();
  SERIAL_IO.println(F("{\"info\":\"press 'c' + Enter in 2s to calibrate\"}"));
  while (millis() - t0 < 2000) {
    if (SERIAL_IO.available()){
      String ln = SERIAL_IO.readStringUntil('\n'); ln.trim();
      if (ln.equalsIgnoreCase("c") || ln.indexOf("\"cmd\":\"calibrate\"")>=0){
        robot.calibrateNeutral();
        Protocol::sendOk("boot_calibrated");
      }
      break;
    }
    delay(5);
  }
#endif
}

void loop(){
  g_irMenu.countLoop();
  if (Protocol::readLine(SERIAL_IO, g_rxLine)) handleJson(g_rxLine);
  robot.update();
    // Peripherals polling
  #if RFID_ENABLED
    if (g_rfid.poll()){
      g_irMenu.recordRfid();
      g_lastRfid = g_rfid.lastUid();
      SERIAL_IO.print(F("{\"ok\":true,\"event\":\"rfid\",\"uid\":\""));
      printJsonEscaped(g_lastRfid);
      SERIAL_IO.println(F("\"}"));
  #if LCD_ENABLED
      // Do not steal the screen while user is browsing menus.
      if (!g_lcdStatus.isPinned()){
        char tail[9];
        size_t rlen = g_lastRfid.length();
        size_t start = (rlen > 8) ? (rlen - 8) : 0;
        uint8_t ti = 0;
        for (size_t p = start; p < rlen && ti < 8; ++p) tail[ti++] = g_lastRfid[p];
        tail[ti] = '\0';
        g_lcdLineTmp = tail;
        g_lcdStatus.showTo(LCD_TGT_1, "RFID", g_lcdLineTmp);
      }

      // Normalize UID (remove non-alnum, uppercase)
      char norm[17];
      uint8_t ni = 0;
      for (size_t _i = 0; _i < g_lastRfid.length(); ++_i){
        char c = g_lastRfid[_i];
        if ((c >= '0' && c <= '9') || (c >= 'A' && c <= 'F') || (c >= 'a' && c <= 'f')){
          if (c >= 'a' && c <= 'f') c = c - ('a' - 'A');
          if (ni < sizeof(norm) - 1) norm[ni++] = c;
        }
      }
      norm[ni] = '\0';

      // Owner UID (uppercase, no separators)
      if (isOwnerUid(norm)){
        // Greet owner only when LCD is not pinned by menu UI.
        if (!g_lcdStatus.isPinned()){
          g_lcdStatus.showTo(LCD_TGT_1, "Merhaba", "Sahip");
        }
        playCuteSound(CUTE_SUPER_HAPPY, true);
        // Enqueue sequence: walle then three bb8 variants
        enqueueSong(SONG_WALLE);
        enqueueSong(SONG_BB8_1);
        enqueueSong(SONG_BB8_2);
        enqueueSong(SONG_BB8_3);
      }
  #endif
    }
  #endif
  #if ULTRA_ENABLED
    if (g_ultra.measureIfDue(ULTRA_MEASURE_INTERVAL_MS)){
      g_ultraCm = g_ultra.lastCm();
    }
    if (g_avoidEnable && robot.getMode()==MODE_SKATE){
      if (!isnan(g_ultraCm) && g_ultraCm>0 && g_ultraCm < AVOID_DISTANCE_CM){
        robot.setDriveCmd(AVOID_REVERSE_SPEED);
  #if LCD_ENABLED
      char cmBuf[12];
      ltoa((long)g_ultraCm, cmBuf, 10);
      g_lcdLineTmp = cmBuf;
      g_lcdLineTmp += "cm";
      g_lcdStatus.show("AVOID", g_lcdLineTmp);
      pushAlert(F("OBSTACLE DETECTED"));
  #endif
  // Song queue processing lives in the main BUZZER section below.
      }
    }
#if ULTRA_ENABLED && BUZZER_ENABLED
    // Parking-style proximity beeps while sitting in avoid-mode
    if (g_avoidEnable && robot.getMode()==MODE_SKATE){
      if (!isnan(g_ultraCm) && g_ultraCm>0 && g_ultraCm < AVOID_DISTANCE_CM){
        unsigned long nowp = millis();
        if (g_ultraCm <= AVOID_CONTINUOUS_CM){
          // Very close: start a sustained/continuous tone
          if (!g_proxContinuousOn){
            if (g_buzzerBothEnabled){
              g_buzzer.beepOn(BUZZER_OUT_LOUD, g_buzzerFreqLoud, 0);
              g_buzzer.beepOn(BUZZER_OUT_QUIET, g_buzzerFreqQuiet, 0);
            } else {
              uint16_t f = (g_buzzerDefaultOut==BUZZER_OUT_LOUD)?g_buzzerFreqLoud:g_buzzerFreqQuiet;
              g_buzzer.beepOn(g_buzzerDefaultOut, f, 0);
            }
            g_proxContinuousOn = true;
          }
        } else {
          // PROPORTIONAL parking beeps
          // Scale linearly from 60ms (at 8cm) to 800ms (at 25cm)
          unsigned long interval = (unsigned long)((g_ultraCm - AVOID_CONTINUOUS_CM) * 43.5f + 60.0f);
          interval = constrain(interval, 50, 1000);

          if (nowp - g_lastProxBeepMs >= interval){
            g_lastProxBeepMs = nowp;
            if (g_buzzerBothEnabled){
              g_buzzer.beepOn(BUZZER_OUT_LOUD, g_buzzerFreqLoud, 40);
              g_buzzer.beepOn(BUZZER_OUT_QUIET, g_buzzerFreqQuiet, 40);
            } else {
              uint16_t f = (g_buzzerDefaultOut==BUZZER_OUT_LOUD)?g_buzzerFreqLoud:g_buzzerFreqQuiet;
              g_buzzer.beepOn(g_buzzerDefaultOut, f, 40);
            }
          }
          if (g_proxContinuousOn){
            g_buzzer.stop();
            g_proxContinuousOn = false;
          }
        }
      } else {
        // If ultrasonic no longer in range/valid, ensure sustained tone is stopped
        if (g_proxContinuousOn){
          g_buzzer.stop();
          g_proxContinuousOn = false;
        }
      }
    }
#endif
  #endif

#if IR_ENABLED
  // if (g_ir.poll(g_irKey)){
  //   g_irMenu.onKey(g_irKey, robot);
  // }
  g_irMenu.tick(robot);
#endif

#if LCD_ENABLED
  g_lcdStatus.tick();
#endif

#if BUZZER_ENABLED
  // First, allow queued songs to start if no song currently playing
  processSongQueue();
  g_song.update();
  g_buzzer.update();
#endif
  
  // Heartbeat timeout safety
  if (HEARTBEAT_TIMEOUT_MS > 0){
    bool linkNow = (millis() - lastHeartbeatMs) <= HEARTBEAT_TIMEOUT_MS;
    if (linkNow && !g_linkAlive){
      g_linkAlive = true;
      g_linkEverAlive = true;
      playCuteSound(CUTE_CONNECTION, true);
    } else if (!linkNow && g_linkAlive && g_linkEverAlive){
      g_linkAlive = false;
      playCuteSound(CUTE_DISCONNECTION, true);
    }
  }
  if (HEARTBEAT_TIMEOUT_MS>0 && (millis() - lastHeartbeatMs > HEARTBEAT_TIMEOUT_MS)){
    robot.estop();
  }
  // Poll radio and update NEMA controller
  #if EBYTE_ENABLED
  g_ebyteRadio.poll();
  #endif
  g_nema.update();
  #if DS18_ENABLED
  g_ds18.update();
  #endif
  #if HALL_ENCODER_ENABLED
  g_hall0.update();
  g_hall1.update();
  #endif
  // Telemetry periodic output
  if (telemetryOn && millis() - lastTelemetryMs >= telemetryInterval){
    lastTelemetryMs = millis(); robot.imu.read();
    printTelemetryJson();
  }
  // periodic maintenance for neopixel request retries/acks
  neopixelTick();
  // subtle idle breathing / micro-motion when enabled by the bridge
  livelinessTick();
}

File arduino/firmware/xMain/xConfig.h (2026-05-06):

#ifndef ROBOT_CONFIG_H
#define ROBOT_CONFIG_H
#include <Arduino.h>

// Board serial
#define ROBOT_SERIAL_BAUD 115200
// Select serial port for NDJSON link.
// SERIAL_IO_PORT options:
//   0 = Serial
//   1 = Serial1 (if available)
//   2 = Serial2 (if available)
//   3 = Serial3 (if available)
#ifndef SERIAL_IO_PORT
#if defined(ARDUINO_AVR_MEGA2560) || defined(ARDUINO_AVR_MEGA) || defined(__AVR_ATmega2560__)
#define SERIAL_IO_PORT 3
#else
#define SERIAL_IO_PORT 0
#endif
#endif

// You can still override everything by defining SERIAL_IO before including this header.
#ifndef SERIAL_IO
#if SERIAL_IO_PORT == 0
#define SERIAL_IO Serial
#elif SERIAL_IO_PORT == 1 && (defined(HAVE_HWSERIAL1) || defined(UBRR1H) || defined(USART1_RX_vect))
#define SERIAL_IO Serial1
#elif SERIAL_IO_PORT == 2 && (defined(HAVE_HWSERIAL2) || defined(UBRR2H) || defined(USART2_RX_vect))
#define SERIAL_IO Serial2
#elif SERIAL_IO_PORT == 3 && (defined(HAVE_HWSERIAL3) || defined(UBRR3H) || defined(USART3_RX_vect))
#define SERIAL_IO Serial3
#else
#define SERIAL_IO Serial
#endif
#endif

// Servo counts (pan/tilt + 2x Pi servo)
#define SERVO_COUNT_TOTAL 4

// Pins – adapt to your wiring
// NOTE: These are PCA9685 channel numbers (0..15) when `SERVO_USE_PCA9685==1`.
// If using direct Arduino pins (SERVO_USE_PCA9685==0), replace with digital pin numbers.
// PCA9685 channel mapping:
//  - 0..15: channels on the board. In this build we use four channels:
//    6 = pan, 9 = tilt, 7 = pi-servo-1 (ear), 8 = pi-servo-2 (ear)
// Pan/Tilt (PCA channel numbers)
#define PIN_PAN   6
#define PIN_TILT  9
// Pi servos (ears) — PCA channels
#define PIN_PI_SERVO_1 7
#define PIN_PI_SERVO_2 8

// Stepper pins (moved to avoid servo overlap)
// New Mega2560 wiring (user-provided)
// Motor1: DIR=12 STEP=11, Motor2: DIR=10 STEP=9
#define PIN_STEPPER1_DIR  12
#define PIN_STEPPER1_STEP 11
#define PIN_STEPPER2_DIR  10
#define PIN_STEPPER2_STEP 9
// Shared enable pin for both NEMA drivers
#ifndef PIN_STEPPER_ENABLE
#define PIN_STEPPER_ENABLE 8
#endif
// Active low by default (A4988/DRV8825 common)
#ifndef STEPPER_ENABLE_ACTIVE_LOW
#define STEPPER_ENABLE_ACTIVE_LOW 1
#endif
// Limit switch pins (optional). Use -1 to disable; active LOW by default.
#ifndef PIN_LIMIT1
#define PIN_LIMIT1 -1
#endif
#ifndef PIN_LIMIT2
#define PIN_LIMIT2 -1
#endif
#ifndef LIMIT_ACTIVE_LOW
#define LIMIT_ACTIVE_LOW 1
#endif

// Pan/Tilt limits
#define PAN_MIN  30
#define PAN_MAX  150
#define TILT_MIN 60
#define TILT_MAX 120

// Motion
#define SPEED_DEG_PER_S 60 // default easing speed

// IMU
#define IMU_I2C_ADDR 0x68

// Link safety & telemetry
#define HEARTBEAT_TIMEOUT_MS 500   // hb gelmezse bu sürede estop
#define TELEMETRY_MIN_INTERVAL_MS 20 // 50 Hz üstü riskli, altını öner

// PID (balance)
#define PID_PITCH_KP  0.8f
#define PID_PITCH_KI  0.02f
#define PID_PITCH_KD  0.05f
#define PID_ROLL_KP   0.8f
#define PID_ROLL_KI   0.02f
#define PID_ROLL_KD   0.05f
#define PID_OUT_LIMIT 15.0f  // deg of corrective hip offset cap
#define PID_SAMPLE_MS 10
#define PID_DEADBAND_DEG 2.0f
#define PID_MAX_ANGLE_DEG 45.0f

// Optional: enable serial-boot calibration prompt
#define BOOT_CALIBRATION_PROMPT 1

// Default poses
// Default poses: index mapping: 0=pan, 1=tilt, 2=pi_servo_1, 3=pi_servo_2
static const uint8_t POSE_STAND[SERVO_COUNT_TOTAL] PROGMEM = {90,90, 90,90};

// Stepper skate balance PID (inverted pendulum)
#define SKATE_KP  18.0f   // speed per degree
#define SKATE_KI  0.0f
#define SKATE_KD  0.8f    // speed per (deg/s)
#define SKATE_SPEED_LIMIT 2000.0f // steps/s cap

// =====================
// Closed-loop stepper PID (Hall feedback)
// Production-safe defaults: conservative gains, reasonable sampling period.
#ifndef STEPPER_PID_KP
#define STEPPER_PID_KP  1.0f
#endif
#ifndef STEPPER_PID_KI
#define STEPPER_PID_KI  0.0f
#endif
#ifndef STEPPER_PID_KD
#define STEPPER_PID_KD  0.05f
#endif
#ifndef STEPPER_PID_INTERVAL_MS
#define STEPPER_PID_INTERVAL_MS 50  // PID update period (ms)
#endif
#ifndef STEPPER_PID_MAX_OUTPUT
// Maximum commanded speed (absolute) the PID can emit (steps/s)
// Default to skate speed limit for safety
#define STEPPER_PID_MAX_OUTPUT SKATE_SPEED_LIMIT
#endif
#ifndef STEPPER_PID_INTEGRAL_LIMIT
// Clamp for integral term to avoid windup (in speed units*sec)
#define STEPPER_PID_INTEGRAL_LIMIT 10000.0f
#endif

// Steps mapping for rotation/translation commands used by IR controller
// Compute steps per revolution from motor full steps and gearbox ratio
// Motor full steps (e.g. NEMA17 = 200)
#ifndef STEPPER_MOTOR_FULLSTEPS
#define STEPPER_MOTOR_FULLSTEPS 200
#endif
// Gearbox reduction ratio expressed as (1 + NUM/DEN)
#ifndef GEARBOX_RATIO_NUM
#define GEARBOX_RATIO_NUM 38
#endif
#ifndef GEARBOX_RATIO_DEN
#define GEARBOX_RATIO_DEN 14
#endif
// Steps per output-shaft revolution (float) = MOTOR_FULLSTEPS * (1 + NUM/DEN)
#ifndef STEPPER_STEPS_PER_REV
#endif
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

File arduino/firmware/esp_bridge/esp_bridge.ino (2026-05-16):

#include <WiFi.h>
#include <ESPmDNS.h>
#include <WebServer.h>
#include <ArduinoJson.h>

#include "config.h"
#include "index.h"
#include "RobotState.h"
#include "UartHandler.h"

HardwareSerial MegaUart(2);
RobotState g_robotState;
WebServer server(HTTP_PORT);
WebServer serverCompat80(80);

// WiFi status tracking
volatile bool g_wifiConnected = false;
volatile bool g_linkAlive = false;

// Response buffer: Mega'dan gelen cevapları tutuyor
StaticJsonDocument<JSON_DOC_SIZE> g_responseBuffer;
volatile bool g_responseReady = false;

// Forward declarations
void setupWiFi();
void setupWebServer();
void registerRoutes(WebServer& s);
void handleSend(WebServer& ctx);
void handleRequest(WebServer& ctx);
void handleHealthz(WebServer& ctx);
void handleRoot(WebServer& ctx);
bool responseMatchesCommand(const JsonDocument& doc, const String& cmd);

void setup() {
    Serial.begin(115200);
    Serial.println("\n\nSentryBOT ESP Bridge Starting (RTOS Mode)...");

    // Setup WiFi and mDNS
    setupWiFi();
    setupWebServer();

    // Initialize UART and tasks (UART2 init happens here)
    initUartTask();
    initLinkTask();

    Serial.println("Bridge Tasks Initialized.");
}

void loop() {
    // Handle HTTP requests
    if (g_wifiConnected && WiFi.status() == WL_CONNECTED) {
        server.handleClient();
        if (HTTP_PORT != 80) {
            serverCompat80.handleClient();
        }
    }
    vTaskDelay(pdMS_TO_TICKS(10));
}

void setupWiFi() {
    Serial.print("Connecting to WiFi: ");
    Serial.println(WIFI_SSID);
    
    WiFi.mode(WIFI_STA);
    WiFi.setSleep(WIFI_PS_NONE);
    WiFi.setAutoReconnect(true);
    WiFi.begin(WIFI_SSID, WIFI_PASS);
    
    int retry = 0;
    const int MAX_RETRY = 20; // 10 seconds
    
    while (WiFi.status() != WL_CONNECTED && retry < MAX_RETRY) {
        delay(500);
        Serial.print(".");
        retry++;
    }
    
    if (WiFi.status() == WL_CONNECTED) {
        g_wifiConnected = true;
        Serial.println();
        Serial.print("WiFi Connected! IP: ");
        Serial.println(WiFi.localIP());
        
        // Setup mDNS
        if (!MDNS.begin(MDNS_HOSTNAME)) {
            Serial.println("MDNS initialization failed");
        } else {
            Serial.print("mDNS initialized as: ");
            Serial.print(MDNS_HOSTNAME);
            Serial.println(".local");
            MDNS.addService("http", "tcp", HTTP_PORT);
        }
    } else {
        g_wifiConnected = false;
        Serial.println();
        Serial.println("WiFi connection failed. Bridge will operate in UART-only mode.");
    }
}

void setupWebServer() {
    registerRoutes(server);
    
    server.begin();
    Serial.print("HTTP server started on port ");
    Serial.println(HTTP_PORT);

    if (HTTP_PORT != 80) {
        registerRoutes(serverCompat80);
        serverCompat80.begin();
        Serial.println("HTTP compatibility server started on port 80");
    }
}

void registerRoutes(WebServer& s) {
    s.on("/", HTTP_GET, [&s]() { handleRoot(s); });
    s.on("/send", HTTP_POST, [&s]() { handleSend(s); });
    s.on("/request", HTTP_POST, [&s]() { handleRequest(s); });
    s.on("/healthz", HTTP_GET, [&s]() { handleHealthz(s); });
}

void handleSend(WebServer& ctx) {
    // /send: fire-and-forget JSON to Mega
    if (!ctx.hasArg("plain")) {
        ctx.send(400, "application/json", "{\"ok\":false,\"error\":\"no payload\"}");
        return;
    }
    
    String payload = ctx.arg("plain");
    MegaUart.println(payload);
    
    ctx.send(200, "application/json", "{\"ok\":true}");
}

void handleRequest(WebServer& ctx) {
    // /request: send JSON to Mega and wait for response
    if (!ctx.hasArg("plain")) {
        ctx.send(400, "application/json", "{\"ok\":false,\"error\":\"no payload\"}");
        return;
    }
    
    String payload = ctx.arg("plain");
    StaticJsonDocument<256> reqDoc;
    String requestedCmd = "";
    if (deserializeJson(reqDoc, payload) == DeserializationError::Ok) {
        if (reqDoc["cmd"].is<const char*>()) {
            requestedCmd = reqDoc["cmd"].as<String>();
        }
    }

    g_responseReady = false;  // Clear previous response
    MegaUart.println(payload);
    
    // Wait for response with timeout (500ms)
    unsigned long startTime = millis();
    const unsigned long RESPONSE_TIMEOUT = 500;
    
    while ((millis() - startTime) < RESPONSE_TIMEOUT) {
        if (g_responseReady) {
            if (responseMatchesCommand(g_responseBuffer, requestedCmd)) {
                String response;
                serializeJson(g_responseBuffer, response);
                ctx.send(200, "application/json", response);
                g_responseReady = false;
                return;
            }
            // Ignore unrelated telemetry/event/heartbeat responses and keep waiting.
            g_responseReady = false;
        }
        delay(5);  // Small delay to allow other tasks
    }
    
    // Timeout: Mega didn't respond in time with a matching response
    ctx.send(504, "application/json", "{\"ok\":false,\"error\":\"timeout_waiting_for_mega_response\"}");
}

void handleHealthz(WebServer& ctx) {
    // /healthz: basic status check
    bool uartOk = (MegaUart.available() >= 0); // simple check
    bool linkOk = g_linkAlive;
    
    StaticJsonDocument<256> doc;
    doc["ok"] = uartOk && g_wifiConnected;
    doc["wifi"] = g_wifiConnected;
    doc["link"] = linkOk;
    doc["rssi"] = WiFi.RSSI();
    
    String response;
    serializeJson(doc, response);
    ctx.send(200, "application/json", response);
}

void handleRoot(WebServer& ctx) {
    ctx.send(200, "text/html", INDEX_HTML);
}

bool responseMatchesCommand(const JsonDocument& doc, const String& cmd) {
    if (cmd.length() == 0) return true;
    if (!doc["ok"].is<bool>() && !doc.containsKey("ok")) return false;
    if (doc["telemetry"].is<bool>() && doc["telemetry"].as<bool>()) return false;
    if (doc.containsKey("event") || doc.containsKey("info")) return false;

    if (cmd == "temp_read") return doc.containsKey("temps");
    if (cmd == "get_state") return doc.containsKey("pitch") && doc.containsKey("roll");
    if (cmd == "ultra_read") return doc.containsKey("cm");
    if (cmd == "rfid_last") return doc.containsKey("rfid");
    if (cmd == "imu_read") return doc.containsKey("msg");

    // For control commands, any non-telemetry/event json is acceptable.
    return true;
}

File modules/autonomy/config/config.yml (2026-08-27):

runtime:
  auto_start: true
  start_on_gateway_boot: true

defaults:
  loop_interval_ms: 500
  boredom_threshold_s: 20
  alone_threshold_s: 120
  mood:
    decay_rate: 0.5
    anger_threshold: 38
    furious_threshold: 75
    initial_happiness: 50
    initial_energy: 100
    max_happiness: 100
    max_energy: 100
    needs:
      social:
        initial: 50
        decay_per_s: 0.08
        interaction_fill: 18
      stimulation:
        initial: 40
        growth_per_s: 0.12
        interaction_drain: 12
      rest:
        initial: 80
        drain_per_s: 0.06
        sleep_fill: 35
  body_language:
    profiles:
      joy:
        pan_delta: 6
        tilt_delta: 4
        event: autonomy.joy
      curiosity:
        pan_delta: 8
        tilt_delta: 3
        event: autonomy.curious
      fear:
        pan_delta: 10
        tilt_delta: 6
        event: autonomy.alert
      tired:
        pan_delta: 2
        tilt_delta: 2
        event: autonomy.tired
      sadness:
        pan_delta: 3
        tilt_delta: 5
        event: autonomy.sad
      neutral:
        pan_delta: 4
        tilt_delta: 3
        event: autonomy.neutral
  lights:
    default_mode: breathe
    palettes:
      calm_violet:
      - 120
      - 80
      - 255
      sunset_gold:
      - 255
      - 170
      - 60
      alert_red:
      - 255
      - 45
      - 45
      ocean_teal:
      - 30
      - 180
      - 255
      arctic_white:
      - 255
      - 255
      - 255
      forest_green:
      - 60
      - 200
      - 90
      ember_orange:
      - 255
      - 110
      - 40
      polar_blue:
      - 90
      - 150
      - 255
endpoints:
  arduino: '@gateway/arduino'
  neopixel: '@gateway/neopixel'
  speak: '@gateway/speak'
  ollama: '@gateway/ollama'
  speech: '@gateway/speech'
  interactions: '@gateway/interactions'
  expression: '@gateway/expression'
  oled_faces: '@gateway/oled_faces'
  state_manager: '@gateway/state'
  animate: '@gateway/animate'
  vlm: '@gateway/vlm'
  vision: '@gateway/vlm'
  camera: '@gateway/camera'
  notifier: '@gateway/notify'
  autonomy: '@gateway/autonomy'
  agent_core: '@gateway/agent'
owner:
  name: "Emir"
  aliases:
    - "emir"
    - "sahip"
    - "patron"
    - "reis"
  presence_timeout_s: 25
  greeting: "Hoş geldin {name}! Seni gördüğüme çok sevindim."
behaviors:
  idle:
    enabled: true
    actions:
    - look_around
    - blink
    - sigh
    - stretch
    - monologue
  idle_tree:
    enabled: true
    interval_s: 6
    fallback_to_llm: true
    path: modules/autonomy/config/idle_behaviors.yml
  curiosity:
    enabled: true
    face_tracking: true
    sound_reaction: true
  sleep:
    enabled: true
    start_hour: 3
    end_hour: 6
    wake_up_action: stretch
llm:
  enabled: true
  model: qwen3.5:9b
  auto_select_persona: false
  warmup_on_start: true
  prompt_template: 'Sen duyguları olan bir robotsun.


    Şu anki İç Durumun:

    - Mutluluk: {happiness}/100 (Düşükse üzgün, yüksekse neşeli)

    - Enerji: {energy}/100 (Düşükse uykulu/yorgun)

    - Sıkılma: {is_bored} (Evet ise ilgi istiyorsun)

    - Son Etkileşim: {last_interaction_ago} saniye önce

    - Saat: {time}


    GÖREV: Bu duruma uygun, çok kısa (maksimum 10 kelime) bir iç ses cümlesi kur.

    - Robotik değil, canlı bir karakter gibi konuş.

    - Sadece söyleyeceğin cümleyi yaz.
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

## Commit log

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2025-09-24 Refactor biped robot firmware: - Remove outdated README.md and replace with comprehensive documentation covering features, setup, command reference, and peripherals. - Update xServoBus.h to support P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
    [xConfig.h, xMain.ino]
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2025-09-24 Feature: add Logwrapper module for centralized logging with FastAPI integration
    - Introduced lightweight centralized logging service to aggregate logs across modules
    - Console + rotating file handlers; supports JSON and human-readable formats
    - In-memory ring buffer (readable via optional FastAPI router)
    - Redirected Python warnings to logging; per-module level overrides supported
    - Library helpers: init_logging() and get_router() for easy embedding
    - CLI/service entrypoint: python -m modules.logwrapper.xLogService
    - Configuration at modules/logwrapper/config/config.yml with env overrides (LOG_LEVEL, LOG_FILE)
    - Gateway: attempts init_logging() on startup; failures are non-blocking for other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
    [config.yml]
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2025-09-24 Feature: add Notifier module with Telegram/Discord integrations and API
    - Introduced Notifier service as a simple bridge for Telegram and Discord notifications
    - Added FastAPI endpoints:
    - GET /notify/healthz
    - POST /notify/telegram { text } (requires token/chat_id in config)
    - POST /notify/discord { text } (requires webhook in config)
    - POST /notify/test (sends a test message to configured targets)
    - Configuration scaffold (modules/notifier/config/config.yml):
    - telegram: { token, chat_id }
    - discord: { webhook_url }
    - enable flags per provider and optional timeouts/retries
    - Safe behavior when credentials are missing: provider is skipped and clear error is retu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
    [config.yml]
2025-09-24 Feature: add OTA module with configuration, API, and avrdude upload workflow
    - Introduced OTA service for Arduino firmware uploads via avrdude
    - Watches ota.watch_dir for latest .hex artifact; versions artifacts with single-shot SHA256
    - Skips duplicate uploads based on filename + hash
    - Generates avrdude command from config (board/programmer/flags under ota.board & ota.avrdude)
    - Added FastAPI router under /ota with endpoints:
    - GET /ota/healthz
    - POST /ota/scan_once
    - POST /ota/upload
    - GET /ota/versions
    - POST /ota/versions/clear
    - Configuration: modules/ota/config/config.yml
    - Service entrypoint: python -m modules.ota.xOTAService
    - Gateway integration: router can be mounted u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
    [config.yml]
2025-09-24 Feature: add NeoPixel automation engine with API and configuration
    - Introduced lightweight rule engine to select Base (continuous) and Transient (short) LED effects
    - Connects to existing NeoPixel HTTP service under /neopixel
    - Hardware mapping prepared for Jewel (7) + Stick (16); currently applies to full strip
    - FastAPI integration: xInteractionsService.create_app(); default port 8095
    - Endpoints:
    - GET /interactions/state
    - POST /interactions/event { type, data? }
    - POST /interactions/effect { name, duration_ms? }
    - POST /interactions/base { name, color? }
    - Gateway integration: router can be mounted; rules call NeoPixel endpoints directly
    - Configuration (modules/interact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
    [config.yml]
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2025-09-24 Feature: add Vision Bridge module with API, configuration, and core functionality
    - Introduced Vision Bridge to accept vision-processor outputs and forward robot commands
    - API endpoint:
    - POST /vision/track { head_tilt, head_pan, drive? } → bridges to Arduino "track" command
    - Service entrypoint: python -m modules.vision_bridge.xVisionBridgeService
    - Gateway integration: mountable via include.vision_bridge=true in Gateway config
    - Configuration scaffold (modules/vision_bridge/config/config.yml) for target endpoints, timeouts, and auth
    - Input validation, basic rate limiting, and clear error reporting
    - Logging through centralized logwrapper; emits forwarded command summaries
    - Documenta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
    [config.yml]
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2025-12-19 feat(notifier): enhance Telegram bot functionality with command routing and quiet hours management
    - Added command router to handle various Telegram commands and route them to appropriate services.
    - Implemented quiet hours feature to suppress notifications during specified times.
    - Updated README with installation instructions and detailed bot commands.
    - Enhanced API to support optional chat_id in Telegram notifications.
    - Introduced environment variable support for configuration via .env file.
    - Improved error handling and logging throughout the notifier service.
    - Refactored Telegram bot to support polling and command execution in an asynchronous manner.
    - Added support for sending photo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
    [config.yml]
2026-01-10 feat(arduino): update pin map and add IR/buzzer config
    [xConfig.h]
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2026-01-10 feat(arduino): dual LCD + boot UI + buzzer/IR config
    [xConfig.h]
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2026-01-12 arduino: try alternate MPU6050 address (0x69) if 0x68 fails; check both addresses at boot
    [xMain.ino]
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2026-01-17 fix(notifier, log): normalize telegram tokens and suppress noisy access logs
    [config.yml]
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2026-01-20 fix(neopixel): resolve pin conflict (Neo=6, HC=22), enable RGBW, and add startup anim
    [xConfig.h]
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2026-01-27 config/main: add buzzer EEPROM addresses and continuous-avoid threshold; load/save freqs; proximity parking beeper behavior; force RFID LCD refresh
    [xConfig.h, xMain.ino]
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2026-01-31 arduino(firmware): allow RFID repeat and re-emission; add non-blocking song queue and buzzer isPlaying
    [xConfig.h, xMain.ino]
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2026-02-06 fix: remove stray #endif in xConfig.h header guard
    [xConfig.h]
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2026-03-01 chore: auto-load Hall PPR & PID, emit NDJSON stall events
    [xMain.ino]
2026-03-01 Apply PR review feedback: setEnable safety fix, setTargetSpeed PID reset, JSON doc fix, CSV doc update, bare except fix, duplicate ifndef guard removal
    [xConfig.h]
2026-03-03 fix(gateway): wire vision processor and expand module mount coverage
    [config.yml]
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2026-03-03 Improve runtime stability and reduce noisy logs
    [config.yml]
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2026-03-06 fix: address PR review comments (escaping, reserve, healthz ok, logo stop_animation, driver tests)
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2026-03-18 Enhance idle action visuals and improve neopixel error logging
    [config.yml]
2026-03-18 feat(oled_faces): fix bitmap alignment and optimize for 128x64 SSD1306
    - Pre-converted Irisoled bitmaps to Page-Major format for performance
    - Updated config to 128x64 resolution
    - Removed redundant 128x32 assets
    [config.yml]
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2026-03-19 fix(config): set speech listening to false in configuration feat(speech): add timestamp to last speech result and handle non-empty text refactor(speech): improve result callback handling with locks f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
    [config.yml]
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2026-03-31 fix(vision_bridge): adjust model/load and face processing
    [config.yml]
2026-04-11 fix(config): update ultrasonic and buzzer pin assignments
    [xConfig.h]
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2026-04-13 fix(ollama): standardize defaults and model inheritance
    [config.yml]
2026-04-13 fix(vlm-bridge): align endpoint defaults and provider guards
    [config.yml]
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2026-04-20 Centralize Ollama URL via agent.yaml and stabilize Pi camera/VLM/Piper
    [config.yml, xConfig.h]
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2026-04-28 refactor(vlm_bridge): update configuration loader and model settings
    - Improve VLM configuration structure
    - Enhance config_loader with robust parameter handling
    - Update model and API settings for better stability
    [config.yml]
2026-04-29 feat(arduino): implement robust ESP32 UART communication layer
    - Add dynamic link_alive calculation with configurable timeout
    - Implement ring buffer with character validation in UartHandler
    - Add stale buffer timeout for communication recovery
    - Configure aggressive timing constants (200ms intervals, 1000ms timeout)
    - Handle parse errors gracefully without link dropout
    [config.h]
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2026-04-29 config(arduino): optimize Mega timing and communication settings
    - Update telemetry and heartbeat intervals for link stability
    - Configure timeout thresholds for robust communication
    - Fine-tune sensor polling rates and LCD update timing
    - Prepare configuration for real-time command responsiveness
    [xConfig.h]
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2026-05-06 fix(esp-bridge): make HTTP handlers work on both server contexts
    Refactor request handlers to receive the active WebServer instance so routes behave
    correctly on both configured ports and command responses are matched more reliably.
    [esp_bridge.ino]
2026-05-06 feat(esp-web): refresh dashboard controls for menu navigation
    Update tab switching and menu shortcut payloads so web controls match the current
    on-device menu model, including explicit sound output selection defaults.
2026-05-06 fix(xmain): stabilize LCD rendering and live sensor menu flow
    Rework menu transitions, redraw invalidation, and sensor refresh paths so HOME/IMU/TEMPS
    pages render consistently, live temperatures update on demand, and obsolete remote menu flow is removed.
    [xConfig.h, xMain.ino]
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2026-05-16 Revert "Merge pull request #125 from WhoIsMrSentry/pr/04-gateway-camera-admin"
    This reverts commit 5933067857dcf851d4425c687ebf18012a7b6329, reversing
    changes made to 8a46539c20e0eaa7147737f04bff45d1a0541342.
    [config.yml]
2026-05-16 Revert "Merge pull request #124 from WhoIsMrSentry/pr/03-agent-core-profiles"
    This reverts commit 8a46539c20e0eaa7147737f04bff45d1a0541342, reversing
    changes made to 914e1d9b44a214924a8ec48fa4a96537e4f89da2.
    [config.yml]
2026-05-16 Revert "Merge pull request #123 from WhoIsMrSentry/pr/02-remote-vlm-bridge"
    This reverts commit 914e1d9b44a214924a8ec48fa4a96537e4f89da2, reversing
    changes made to be695022539dd1593c22f9e813b4290744c962a2.
    [config.yml]
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2026-05-16 fix(esp): improve WiFi stability and HTTP keep-alive to ESP bridge
    Disable WiFi sleep and enable auto-reconnect on ESP32. Reuse a requests
    Session for esp_http transport. Remove stray UTF-8 BOM from gateway config.
    [config.yml, esp_bridge.ino]
2026-05-16 fix(wakeword): keep STT open after wake phrase; fix Google key wiring
    Ignore wakeword-only finals and add a grace period before stop_on_final.
    Restart speech listener on /speech/start. Skip LLM for wake-only text.
    Surface GOOGLE_API_KEY via config loader and /ollama/healthz.
    [config.yml]
2026-05-16 fix(pi): vosk install helper, Google key profile merge, wakeword STT stability
    - Do not let runtime_profile empty api_key override user/env key
    - Inject GOOGLE_API_KEY at agent.yaml load; log when Google profile lacks key
    - Pause openwakeword during command window; disable aggressive auto-calibration
    - Add tools/install_vosk_tr.py and bootstrap warning when Vosk model missing
    - Default ESP profile URL to static IP; speech audio device default
    [config.yml]
2026-05-16 fix(pi): load runtime profile for agent, graceful shutdown, camera fallback
    Autonomy now uses agent_core config_loader so Google AI Studio profile applies.
    run_robot handles SIGINT/SIGTERM; picamera2 failures fall back to OpenCV.
2026-05-16 fix(pi): force Ctrl+C exit and cap camera retry attempts
    Stop OpenCV/VLM camera polling after five failures; second SIGINT or
    4s timeout forces process exit and stops background services.
    [config.yml]
2026-05-16 fix(pi): ESP pause on failure, Gemini 429 backoff, redact API keys in logs
    Pause ESP HTTP after five failures; retry Gemini on 429; skip monologue
    during rate-limit cooldown; improve Ctrl+C feedback.
    [config.yml]
2026-05-16 feat(config): switch default LLM to gemini-3-flash-preview
    Use Gemini 3 Flash API id, disable EN translation bridge for Google
    provider to save quota, per-key 429 cooldown, and clearer API errors.
2026-05-16 feat(speak): auto-select Piper voice by spoken language
    Route TTS to tr or en Piper models from reply text (not STT alone), fall back to dummy when ONNX files are missing for CI, and detect reply language in autonomy before enqueueing speech.
    [config.yml]
2026-05-16 fix(speak): accept string tone presets; narrow quiet hours to 01:00-05:00
    Coerce quiet-hours tone labels like calm into rate/volume dicts so TTS no longer crashes. Restrict speech_quiet_hours to 01:00-05:00 instead of 23:00-07:00.
    [config.yml]
2026-05-16 fix(speech): dual-decode STT tr/en and lock Piper voice per reply
    Always run vosk-tr and vosk-en on each utterance and pick the higher-scoring transcript so English is not misread as Turkish garbage. Lock Piper voice from reply language so long answers do not mix TR and GLaDOS.
    [config.yml]
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2026-05-17 fix(speech): lock session language from STT through LLM and TTS
    Propagate STT language to agent progress/final speech and Piper voice selection. Strengthen dual-decode EN bias, disable per-chunk text language for Piper, and add English progress templates.
    [config.yml]
2026-05-17 fix(agent): gate tool TTS on success; wakeword stops speech
    Speak static tool progress only after a tool returns a usable result. Add wakeword barge-in via /speak/stop and /agent/speech/interrupt so Hey Sentrybot halts TTS and opens listening.
    [config.yml]
2026-05-17 feat(gateway): add shared URL resolver and loopback-safe API security
    [config.yml]
2026-05-17 fix(agent-core,vlm): resolve gateway URL at init and gate vision on camera health
    [config.yml]
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2026-05-17 fix(agent-core): init gateway URL before tools and wire STT suppress on TTS
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2026-05-17 fix(neopixel): add wait mechanism for async animation tests
    The animate() method queues animations asynchronously via background worker
    thread. Test was failing because it checked driver buffer before the worker
    had a chance to process the queued animation.
    Added _wait_for_animations() helper method to NeoRunner that uses queue.join()
    to block until all pending animations complete. Updated test to wait for
    animations before asserting on driver buffer state.
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2026-06-14 fix(interactions): pass RGB colors and emotions through the LED pipeline
    Forward color and emotion hints from rules and manual effects to NeoPixel.
    Document that emotion events drive ears only, not duplicate LED animations.
    [config.yml]
2026-06-14 fix(oled_faces): allow strong emotions during listen and add joy alias
    Keep angry and furious Pip faces visible during STT sessions and map emotion:joy.
    [config.yml]
2026-06-14 fix(camera): honor enabled flag in service, API, and entrypoint
    Skip capture autostart when disabled, gate HTTP start and stream routes, and
    support CAM_ENABLED env override in the config loader.
    [config.yml]
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2026-06-14 fix(gateway): gate capture, IMX500, and VLM stream on camera availability
    Expose _camera_hardware_available and skip stream autostart when disabled.
2026-06-14 fix(vlm_bridge): harden processor when camera hardware is unavailable
    Refuse local capture without hardware, split context vs live camera checks,
    and default to remote processing with follow disabled.
    [config.yml]
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2026-06-15 feat(oled_faces): sync Pip eyes motor from esp-bridge-mcp-robot
    Import the latest procedural eye engine: 31 moods, 17 gesture moves,
    9 activities, gesture face-swap, smoke FX, and smoothstep primitives.
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2026-06-28 chore: add missing opencode skills wrappers and esp_link smoke tests
    28 Haziran 2026 — 2 commit: opencode skills → esp_link tests
2026-06-28 chore: release v5 consolidated — single-center AI, graph UI, cleanup, test fixes
    17 commit boyunca 24-28 Haziran 2026
2026-06-28 fix(graph-ui): track graph.db.zst for GitHub Pages deployment
    .codebase-memory/ is gitignored, but graph.db.zst (4.3 MB) and artifact.json
    must be tracked so the deploy workflow can generate the graph visualization data.
2026-06-28 fix(graph-ui): track graph.db.zst for GitHub Pages deployment
    gitignore negate exception for .codebase-memory/graph.db.zst and artifact.json
2026-06-28 fix(graph-ui): correct GitHub Pages base URL from /Project-SentryBOT-V5/ to /SentryBOT/
    Repo renamed, base path must match current repo name for assets to resolve.
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2026-07-05 fix(ci): guard cv2 import and switch to opencv-python-headless
    - Switch opencv-python to opencv-python-headless in requirements.txt
    to avoid libGL.so.1 dependency on CI runners
    - Wrap import cv2 in try/except in processor.py, cascade_loader.py,
    and face_manager.py so modules bootstrap gracefully when cv2
    is unavailable
    - Make load_frontal_face_cascade return None when cv2 is absent
    (caller already guards against None)
2026-07-05 fix(ci): pin opencv-headless to <5.0 and guard CascadeClassifier
    - Pin opencv-python-headless to <5.0 in vlm_bridge and
    remote_multimodal_server requirements.txt (OpenCV 5.x removed
    CascadeClassifier API)
    - Guard cascade_loader.load_frontal_face_cascade with
    hasattr(cv2, 'CascadeClassifier') for graceful fallback
    regardless of OpenCV version
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2026-07-09 fix(graph-ui): port MCP layout3d.c algorithm into static export script
    Static GitHub Pages export used an unrelated ad-hoc spring layout
    (label-sphere seed, weak repulsion, no anchor), producing a visibly
    different shape from the live localhost:9749 MCP view (comet-tail vs
    compact sphere). Port the exact ring-seed + call-depth BFS + Barnes-Hut
    + anchor-spring optimization from codebase-memory-mcp's layout3d.c so
    both views render identically.
2026-07-09 fix(ollama): apply extracted action tags on autonomy fallback chat
    Wire extract_llm_tags into chat responses so tag-based hardware actions
    can run when autonomy falls back to the ollama module.
2026-07-09 feat(agent_core): add fast-path native tool loop and LLM streaming
    Skip tri-layer for short prompts, return real step actions, stream persona
    tokens into the speech arbiter, and expose native_tools on HTTP step endpoints.
    [config.yml]
2026-07-09 feat(speech): multilingual STT decode and Piper fallback TTS
    Add ambiguous dual-decode, language-aware utterance handling, wakeword
    tuning, and pyttsx3 fallback when Piper voices are missing.
    [config.yml]
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2026-07-11 fix(speech): keep ALSA device when merge config passes null
    Shared mic capture must not lose plughw:0,0 when speech config
    loads device: null from agent.yaml after wakeword bootstrap.
2026-07-11 fix(wakeword): merge agent.yaml overrides into module config
    Load wakeword settings from config/agent.yaml when present and inherit
    speech.audio.device when the wakeword device is unset.
2026-07-11 feat(wakeword): resolve openWakeWord pretrained models at runtime
    Support pretrained_models (e.g. hey_mycroft) with auto-download and switch
    away from the missing custom hey_sentribot.onnx artifact.
    [config.yml]
2026-07-11 fix(speech): keep vosk wakeword fallback alive without webrtcvad
    Disable wakeword VAD by default and log+skip when webrtcvad is missing
    instead of stopping the listener thread.
    [config.yml]
2026-07-11 fix(wakeword): restore ALSA mic capture and builtin hey_mycroft catalog
    Use ALSA for plughw devices instead of falling back to PortAudio default,
    embed openWakeWord model URLs when the Pi wheel has an empty MODELS
    catalog, and point vosk fallback at vosk-en for hey mycroft.
    [config.yml]
2026-07-11 fix(wakeword): load onnx models when inference_framework is onnx
    Prefer .onnx assets over previously downloaded .tflite files, download
    the correct framework variant, and reject undersized model files.
2026-07-11 fix(interactions): coordinate companion modes and pause idle LED animations
    [config.yml]
2026-07-11 fix(neopixel): block animation conflicts and map VU gradient by stick position
    [config.yml]
2026-07-11 fix(companion): dispatch wake_spin and VU immediately on wakeword
    Companion rules now fire in push_event without waiting for the tick loop, VU auto-enters listen_vu from off, idle animations are suppressed during companion, and wakeword/speech use in-process interactions wiring.
    [config.yml]
2026-07-11 feat(speech): add configurable log-scaled stereo VU normalization
    Replace raw peak/32767 scaling with noise-floor and speech-ceiling mapping, per-channel gain, and a configurable RMS window so Pi microphone levels drive the LED VU meter reliably.
    [config.yml]
2026-07-11 fix(neopixel): harden companion renderer lifecycle and VU stale decay
    Add shared frame lock support, deferred mode transitions after wake_spin, stale VU timeout, persistent renderer thread, status introspection, and stricter mode validation.
    [config.yml]
2026-07-11 fix(neopixel): cancel idle animations when companion owns the strip
    Introduce animation generations, buffered animation driver, frame locking, and companion-aware clear/fill/animate guards so BREATHE and preset effects cannot fight wake_spin or VU rendering.
2026-07-11 fix(interactions): isolate VU events and prevent rule replay on tick
    Route speech.audio_level directly to companion VU, keep last event out of tick context, dispatch event rules immediately once, and release expression arbiter claims after timed effects.
    [config.yml]
2026-07-11 fix(speech): emit interaction events synchronously when engine is wired
    Avoid background HTTP latency for listen and VU events when bootstrap wires the in-process interactions engine.
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2026-08-12 fix(neopixel): resolve orchestrator 404 fallback causing wrong LED index
    - Added a dummy /prompt endpoint to neopixel to handle LLM fallback interactions, preventing 404 crashes.
    - Updated behavior planner fallback to default to 'eye' companion mode instead of a full-strip 'breathe'.
    - Mapped EYE_EYEBROW explicitly in NeoPixel animations map to ensure it can be triggered by name.
2026-08-12 fix(neopixel): set jewel center index to 6 (7th LED)
    - Updated NeoPixel config layout so the 7th LED on the jewel is used as the center.
    [config.yml]
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2026-08-12 fix(neopixel): add stop method to NeoRunner for gateway shutdown
    The gateway orchestrator looks for stop/shutdown/close methods to shut down services. NeoRunner lacked these, so the LEDs stayed on during shutdown. Added stop() which turns off companion mode and clears the strip.
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2026-08-16 fix(tui,logs,vision): fix TUI log display, 5-run archive rotation, false hazard suppression, and priority face tracking
    [config.yml]
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2026-08-16 feat: add multi-modal owner reaction, OLED STT text overlay, and fix Ollama SSH bridge
    [config.yml]
2026-08-16 feat: add DoA audio calibration script, fix FaceManager absolute loading and dual persistence, and improve camera probe
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2026-08-26 refactor(system_control/scheduler): fix max_instances in-flight lock and pacing drift
    [config.yml]
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2026-08-27 fix(expression,camera): make status route async and fix gateway camera mount
    [bootstrap_hardware.py]
2026-08-27 perf(runtime_console): resolve TUI freeze by caching events, reducing disk I/O, tab-routing background probes, and set sleep hours 03:00-06:00
    [config.yml]
2026-08-27 fix(voice): deliver STT final results immediately, track in-process last_result, and set Turkish default in config
    [config.yml]
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2026-08-27 fix(voice): downmix stereo microphone chunks to mono for Google STT and disable arduino in gateway
    [config.yml]
2026-08-27 fix(speak): resolve piper model paths from repo root and enable auto language voice routing (tr -> tr_TR, en -> glados)
    [config.yml]
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2026-08-27 fix(vlm_bridge,timeout): increase ollama timeout to 45s and fix google provider text gen in vlm_bridge
    [config.yml]
2026-08-27 fix(ai_provider): disable 3x translation chaining to enable direct fast single LLM call for qwen3.5
    [config.yml]
2026-08-27 fix(chat,arduino): fix NameError in chat.py and optimize arduino request loops to eliminate request storm
    [config.yml]
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
